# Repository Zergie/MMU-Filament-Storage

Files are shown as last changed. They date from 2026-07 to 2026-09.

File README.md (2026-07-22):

<p align="center">
  YAMMU: eight filament paths in twin drawers inside one heated enclosure
</p>

<p align="center">
  <a href="https://discord.gg/QSjW5CMHZC">Join the YAMMU Discord</a>
  
  
</p>

YAMMU is an open, Voron-inspired multi-material unit for FFF printers. It combines eight filament paths, enclosed heated storage, BLDC-driven loading, filament sensing, custom electronics, and Klipper-based control in one machine.

> [!IMPORTANT]
> **YAMMU is a work in progress.** The current goal is reliable loading and unloading before or at the start of a print. Multi-color and multi-material printing are planned, but are not the present focus.

## See the machine

| Complete enclosure | Twin spool carrier | Heated chamber | Custom electronics bay |
| :---: | :---: | :---: | :---: |
| YAMMU enclosure with two filament drawers | Two YAMMU filament spools on the carrier and feeder assembly | YAMMU heater mounted inside the sealed filament chamber | YAMMU electronics bay inside the lower enclosure |

## One system, four jobs

- **Store** — eight spools live in two enclosed drawers built around 2020 extrusion.
- **Dry** — the sealed filament chamber is heated for dry storage while printing.
- **Move** — two BLDC-driven feeders load filament through short inlet paths and toward the extruder.
- **Verify** — switches at the splitter and toolhead let the control system confirm filament progress.

<p align="center">
  Conceptual YAMMU filament path from eight enclosed spools through twin feeders and sensors to the toolhead
</p>

## Built as open hardware

The repository contains the mechanical, electrical, firmware, and assembly material needed to follow the project—not just product renders.

| Area | What is included | Start here |
| --- | --- | --- |
| Mechanical | STEP assembly, printable STLs, and panel DXFs | [CAD](./CAD) · [STLs](./STLs) · [DXFs](./Drawings_DXFs) |
| Electronics | Main, connector, and sensor-board source and manufacturing files | [PCB files](./PCB) - new version soon! |
| Firmware | RP2040 build notes and YAMMU configuration for Klipper / Happy Hare | [Firmware guide](./Firmware/README.md) - new version soon! |
| Assembly | Illustrated assembly manual | [Open the PDF](./Manual/Assembly.pdf) |

## Start exploring

1. Inspect the [STEP assembly](./CAD/Assembly.step) or browse the ready-to-print [STLs](./STLs).
2. Read the [assembly manual](./Manual/Assembly.pdf) to understand the current mechanical build.
3. (unfinished) Review the [PCB feature set](./PCB/README.md) and manufacturing files.
4. (unfinished) Follow the [firmware guide](./Firmware/README.md) for the current RP2040, Klipper, and Happy Hare setup.

## Current roadmap

<p align="center">
  YAMMU roadmap listing all v1.0 working-MMU goals and v1.1 heated-chamber and environmental-monitoring goals
</p>

[View v1.0 progress](https://github.com/Zergie/YAMMU/issues?q=is%3Aissue%20milestone%3Av1.0)
[View v1.1 progress](https://github.com/Zergie/YAMMU/issues?q=is%3Aissue%20milestone%3Av1.1)

## Help build YAMMU

The project especially needs help with prototype testing, CAD, electronics, firmware, and documentation. If you can test the current iteration or improve one part of the system, open an issue or pull request—or join the [YAMMU Discord](https://discord.gg/QSjW5CMHZC).

## Credits and related projects

YAMMU builds on ideas and parts from the wider open-source 3D-printing community, including [Voron Trident](https://github.com/VoronDesign/Voron-Trident), [ERCF v2](https://github.com/Enraged-Rabbit-Community/ERCF_v2), and several community designs documented in the repository history. Review source licenses before redistributing derived parts.

<details>
<summary><strong>Third-party parts and original licenses</strong></summary>

- [Voron Trident](https://github.com/VoronDesign/Voron-Trident) parts — GNU GPL v3
- [ERCF v2](https://github.com/Enraged-Rabbit-Community/ERCF_v2) parts — GNU GPL v3
- [Stronger Compact Spool Auto-Rewinder](https://www.printables.com/model/784434-stronger-compact-spool-auto-rewinder) by rans_1668459 — GNU GPL v2
- [Voron 2.4 front panel handle, hinge, and magnet latch](https://www.printables.com/model/371692-voron-24-front-panel-handle-hinge-magnet-latch/files) by Jason_116929 — CC BY-SA
- [Removable panel/door kit for Voron V2/Trident](https://www.printables.com/model/702768-kit-for-removable-panelsdoors-for-voron-v2trident-/files) by Victor Mateus Oliveira — GNU GPL v3
- [WAGO 221-415 extrusion mount](https://www.printables.com/model/869020-wago-221-415-extrusion-mount-1by5-and-2by5) by Artxime — GNU GPL v3
- [LRS-200 DIN rail mount](https://www.printables.com/model/254538-lrs-200-din-rail-mount) by CrazyIvan359 — Creative Commons 4.0

</details>

Other MMU projects worth exploring include [ERCF v2](https://github.com/Enraged-Rabbit-Community/ERCF_v2), [8-Track](https://github.com/ArmoredTurtle/8-Track-Raven-Alpha), [Primitive Infinite Spool System](https://github.com/Esoterical/PrinterMods/tree/main/Primitive%20Infinite%20Spool%20System), [TradRack](https://github.com/Annex-Engineering/TradRack), and Prusa MMU3.

## License

Repository content is provided under the [GNU General Public License v3.0](./LICENSE). Third-party parts retain their original licenses.

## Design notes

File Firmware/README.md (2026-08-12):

# Build and Flash Firmware Image

1. Refer to [klipper's official installation](https://www.klipper3d.org/Installation.html)

2. `Building the micro-controller` with the configuration shown below.
  * [*] Enable extra low-level configuration options
  * Micro-controller Architecture = `Raspberry Pi RP2040/RP235x`
  * IF USE BOOTLOADER ([see klipper docs](https://www.klipper3d.org/Bootloaders.html#stm32f103-micro-controllers-blue-pill-devices))
    * Bootloader offset = `offset of your bootloader`
  * ELSE
    * Bootloader offset = `No bootloader`
  * Communication interface = `USBSERIAL`
  * GPIO pins to set at micro-controller startup = `gpio4,gpio7`



3. Once the configuration is selected, press `q` to exit,  and "Yes" when  asked to save the configuration.
4. Run the command `make`
5. Flash the MCU
   * IF USE BOOTLOADER
     * Follow the instructions of your bootloader
   * ELSE IF USE NO BOOTLOADER
     * Unplug the Raspberry Pi
     * Hold `Boot` and plug in the Raspberry Pi
     * Run the command `make serialflash FLASH_DEVICE=/dev/serial/by-id/<YOUR USB ID>` for flashing via Serial or
     * OR Copy `~/klipper/out/klipper.uf2` via a windows pc

# Basic configuration
1. Run the `ls /dev/serial/by-id/*` command to get the correct ID number of the RP2040, and set the ID in `mmu.cfg`.
    ```
    [mcu]
    serial: /dev/serial/by-id/usb-1a86_USB_Serial-if00-port0
    restart_method: command
    ```
2. Refer to [klipper's official Config_Reference](https://www.klipper3d.org/Config_Reference.html) to configure the features you want.
3. Refer to [happy-hare's installation guide](https://github.com/moggieuk/Happy-Hare/wiki/Installation) to configure the basic printer settings.
4. In your `mmu/mmu_vars.cfg`, set the `mmu_gear_rotation_distances` variable to `1` for all gaters, as shown below:
    ```
    mmu_gear_rotation_distances: [1, 1, 1, 1, 1, 1, 1, 1]
    ```

# Calibration Steps

```mermaid
graph TD;
    Hardware_Working --> MMU_CALIBRATE_BLDC["MMU_CALIBRATE_BLDC<br/><span style='font-size:10px'>(to map pwm to rpm values))</span>"]
    MMU_CALIBRATE_BLDC --> MMU_CALIBRATE_GEAR["MMU_CALIBRATE_GEAR<br/><span style='font-size:10px'>(to accurately set rotation distance))</span>"]
    MMU_CALIBRATE_GEAR --> MMU_CALIBRATE_BOWDEN["MMU_CALIBRATE_ENCODER<br/><span style='font-size:10px'>(if MMU has an encoder)</span>"]
    MMU_CALIBRATE_BOWDEN --> MMU_CALIBRATE_GATES["MMU_CALIBRATE_GATES<br/><span style='font-size:10px'>(available if MMU has an encoder)</span>"]

    style Hardware_Working stroke-width:0px
```

## Calibate BLDC
Before calibrating the gear rotation distance, calibrate the BLDC motor. Select a gate belonging to the BLDC unit you want to calibrate and run:

`MMU_CALIBRATE_BLDC MOTOR=<0 or 1>`

The calibration automatically determines the minimum usable PWM and measures the motor RPM across the available PWM range. The resulting PWM-to-RPM map is saved to mmu_vars.cfg and is used by Happy Hare for accurate BLDC speed control. Repeat the calibration for both BLDC units.

## Calibrate rotation distance
see [Happy Hare wiki](https://github.com/moggieuk/Happy-Hare/wiki/MMU-Calibration-TypeB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)

## Calibrate bowden length
see [Happy Hare wiki](https://github.com/moggieuk/Happy-Hare/wiki/MMU-Calibration-TypeB#---step-3-calibrate-bowden-length)

## Calibrating gates
see [Happy Hare wiki](https://github.com/moggieuk/Happy-Hare/wiki/MMU-Calibration-TypeB#---step-4-calibrating-individual-gates)

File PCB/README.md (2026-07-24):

<p align="center">
  YAMMU Control Board v05 — KiCad source, fabrication outputs, SMT assembly data, and an interactive BOM
</p>

<p align="center">
  
  
  
</p>

This directory contains the editable KiCad design and manufacturing data for the **YAMMU Control Board v05**. The 100 × 60 mm board brings the RP2040 controller, motor and heater control, fan outputs, servos, end stops, analog sensors, I²C, and power regulation onto one board.

## Board preview

| Component side | Solder side |
| :---: | :---: |
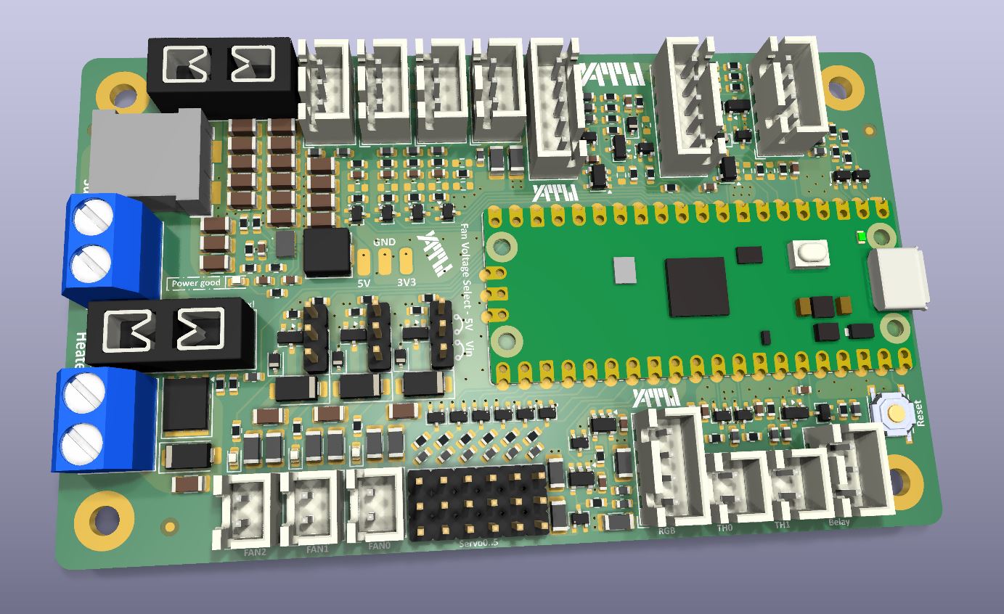
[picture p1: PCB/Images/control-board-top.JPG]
3D render of the populated YAMMU Control Board component side
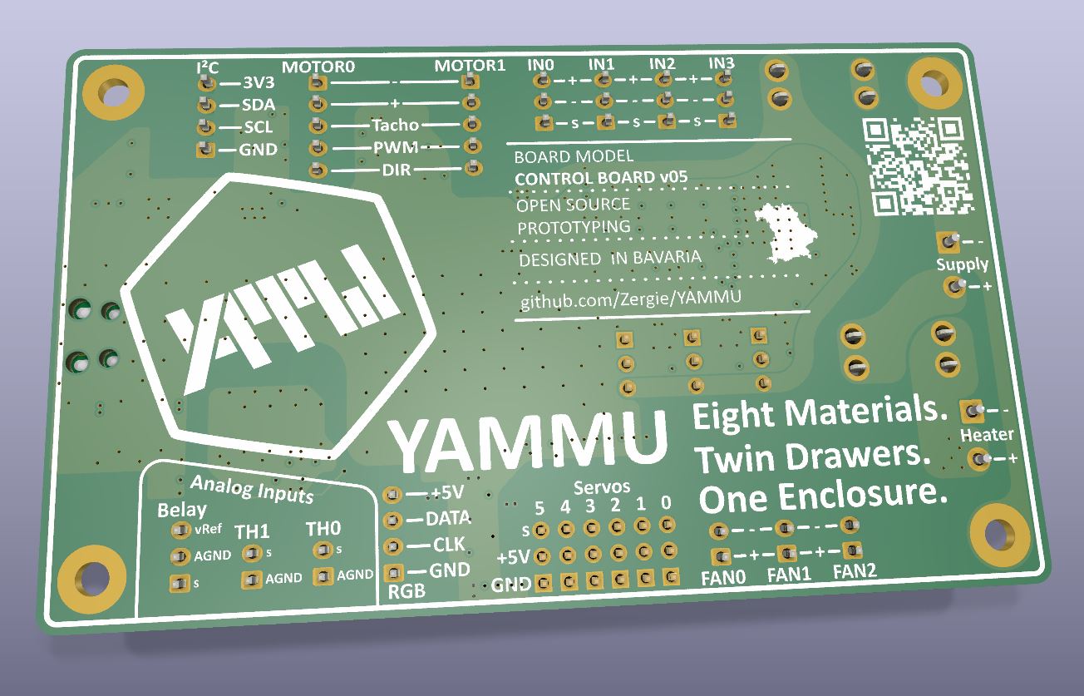
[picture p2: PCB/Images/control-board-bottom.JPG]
3D render of the YAMMU Control Board solder side and connector labels
|  |  |

| Design fact | Checked-in value |
| --- | --- |
| Board revision | `05` |
| KiCad format | KiCad `9.0` |
| Outline | approximately `100 × 60 mm` |
| Board thickness | `1.6 mm` |
| Copper stack | `4 layers` |
| Assembly side | Top-side placement data; the bottom placement file contains no components |
| Placement records | 220 top-side entries |
| DRC snapshot | [0 violations, 0 unconnected pads](./ControlBoard/DRC.rpt) on 2026-07-11 |

## Find the right file

| Use | File |
| --- | --- |
| Open the complete design | [`YAMMU_ControlBoard_v05.kicad_pro`](./ControlBoard/YAMMU_ControlBoard_v05.kicad_pro) |
| Edit the PCB | [`YAMMU_ControlBoard_v05.kicad_pcb`](./ControlBoard/YAMMU_ControlBoard_v05.kicad_pcb) |
| Read the schematic | [Schematic PDF](./ControlBoard/OutputJob/Schematics/YAMMU_ControlBoard_v05.pdf) |
| Manufacture bare boards | [Gerber + drill ZIP](./ControlBoard/OutputJob/YAMMU_ControlBoard_v05_Gerber.zip) |
| Order SMT assembly | [BOM](./ControlBoard/OutputJob/BOM/YAMMU_ControlBoard_v05_BOM.xlsx) + [top-side CPL](./ControlBoard/OutputJob/Centroid/TopCentroid.xlsx) |
| Hand-assemble or inspect | [Interactive BOM](./ControlBoard/Interactive%20Bom/ibom.html) |
| Check component outlines | [Front fabrication drawing](./ControlBoard/OutputJob/BestPlan/YAMMU_ControlBoard_v05-F_Fab.pdf) · [Back fabrication drawing](./ControlBoard/OutputJob/BestPlan/YAMMU_ControlBoard_v05-B_Fab.pdf) |

<p align="center">
  YAMMU PCB manufacturing flow from KiCad source to Gerbers, bare PCB fabrication, and optional SMT assembly using BOM and CPL files
</p>

## Order a bare PCB

[JLCPCB](https://jlcpcb.com/) is one example board house; the same release files can be used with another manufacturer. Prices, capabilities, and form labels change, so treat the provider's current documentation as authoritative.

1. Open the board house's PCB quote page and upload the **ZIP itself**. For JLCPCB, use the [Gerber + drill ZIP](./ControlBoard/OutputJob/YAMMU_ControlBoard_v05_Gerber.zip).
2. Compare the detected result with the design: approximately **100 × 60 mm**, **4 copper layers**, and **1.6 mm** finished thickness. Select the required material, copper weight, solder-mask color, surface finish, quantity, and any other fabrication options; do not rely on automatic detection for choices that are not encoded in the Gerbers.
3. Open the provider's Gerber viewer. Inspect all four copper layers, the continuous board outline, all drills and slots, both masks, and both silkscreens.
4. Save the item to the cart, review manufacturing warnings, shipping, tax, and lead time, then submit the order.

JLCPCB's current walkthrough is available in its [official PCB ordering guide](https://jlcpcb.com/help/article/how-do-i-place-an-order). The online preview is a useful final check, but it does not replace reviewing the KiCad design and release contents.

## Order SMT assembly

An assembly order needs three data sets:

| Upload | What it tells the assembler | This repository |
| --- | --- | --- |
| **Gerbers + drills** | How to fabricate the bare board | [`YAMMU_ControlBoard_v05_Gerber.zip`](./ControlBoard/OutputJob/YAMMU_ControlBoard_v05_Gerber.zip) |
| **BOM** | Which part belongs at each reference designator | [`YAMMU_ControlBoard_v05_BOM.xlsx`](./ControlBoard/OutputJob/BOM/YAMMU_ControlBoard_v05_BOM.xlsx) |
| **CPL / centroid / pick-and-place** | Each component's X/Y position, rotation, and board side | [`TopCentroid.xlsx`](./ControlBoard/OutputJob/Centroid/TopCentroid.xlsx) |

The BOM contains `Designator`, `Comment`, `Footprint`, `Amount`, and `JLCPCB Part #` columns. The CPL contains `Designator`, `Mid X`, `Mid Y`, `Rotation`, and `Layer`. The reference designators must match between the two files.

For a JLCPCB PCBA order:

1. Start a PCB order, upload the corrected Gerber ZIP, and enable **PCB Assembly** before checkout.
2. Select top-side assembly. The current top CPL has 220 placement records. The bottom CPL has no components and is not used for assembly.
3. Upload the BOM and top-side CPL, then let the service process and match them.
4. Review every unmatched or substituted component. Confirm value, package, manufacturer part number or JLCPCB/LCSC part number, stock, and quantity. “No part selected” means that item will not be fitted.
5. Inspect the placement preview at high zoom. Check connector orientation, polarized capacitors and diodes, IC pin 1, rotations, and the board origin. Do not approve the job solely because the files were accepted.
6. Confirm which through-hole, module, connector, or otherwise unsupported parts must be installed by hand after delivery.

JLCPCB documents the current flow in its [official PCBA ordering guide](https://jlcpcb.com/help/article/how-do-i-place-a-pcba-order). Its [BOM/CPL preparation guidance](https://jlcpcb.com/help/article/advice-for-bom-and-cpl-files-preparation) explains reference matching, supported headers, coordinates, and common upload problems.

> [!IMPORTANT]
> Component availability and assembly capabilities are live manufacturing constraints, not properties of this repository. Always re-check part matches and the placement preview for the specific order.

## Use the Interactive BOM

[`Interactive Bom/ibom.html`](./ControlBoard/Interactive%20Bom/ibom.html) is a self-contained browser view generated from the PCB. Download or clone the repository and open the file locally—no KiCad installation or web server is required.

Use it to:

- click a BOM row and highlight the matching footprints on the board;
- pan, zoom, and switch between board sides;
- search by reference, value, or footprint;
- group identical parts and inspect their board locations;
- tick off parts while hand-placing or checking a finished assembly.

The Interactive BOM is an **assembly and inspection aid**. It is not the BOM spreadsheet, not pick-and-place data, and not a file to upload for SMT assembly. Use the `.xlsx` BOM and CPL listed above for the manufacturer.

## License

This PCB is part of the YAMMU open-hardware project. See the repository's [GNU GPL v3.0 license](../LICENSE).

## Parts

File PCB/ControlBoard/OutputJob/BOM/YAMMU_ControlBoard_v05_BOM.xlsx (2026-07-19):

Designator | Comment | Footprint | Amount | JLCPCB Part #
C1,C3 | 1nF | Capacitor_SMD:C_0603_1608Metric | 2 | C1588
C1.1,C1.2,C1.3,C1.4,C1.5,C1.6,C1.7 | 10µF 50V | Capacitor_SMD:C_1206_3216Metric | 7 | C13585
C2,C4,C5,C14 | 10nF | Capacitor_SMD:C_0603_1608Metric | 4 | C57112
C2.1,C2.2,C2.3,C2.4 | 100µF/6,3V | Capacitor_SMD:C_1206_3216Metric | 4 | C15008
C3.1 | 100nF | Capacitor_SMD:C_0603_1608Metric | 1 | C14663
C4.1 | 47pF | Capacitor_SMD:C_0603_1608Metric | 1 | C1671
C5.1 | 3,3nF | Capacitor_SMD:C_0603_1608Metric | 1 | C1613
C6,C15,C18,C19 | 2,2µF | Capacitor_SMD:C_1206_3216Metric | 4 | C50254
C7,C8,C9,C10,C11,C12,C13 | 10µF 50V | Capacitor_SMD:C_1206_3216Metric | 7 | C13585
C16,C17,C20,C21,C22,C23,C24 | 100nF | Capacitor_SMD:C_0603_1608Metric | 7 | C14663
D1,D2,D3,D4,D6,D7,D8,D9,D11,D15,D17,D21,D22,D23,D24,D25,D31,D32,D33,D34,D35 | BAT54SW | Package_TO_SOT_SMD:SOT-323_SC-70 | 21 | C78606
D5,D10 | BZT52C4V7S | Diode_SMD:D_SOD-323 | 2 | C19077439
D12,D16,D18,D27,D28 | RED | LED_SMD:LED_0603_1608Metric | 5 | C2286
D13,D19,D29 | 1N4148 | Diode_SMD:D_SOD-323 | 3 | C2128
D14,D20,D26,D30 | SS34 | Diode_SMD:D_SMA | 4 | C8678
F1,F2 | 10A,3A | Fuse:Fuseholder_Blade_Mini_Keystone_3568 | 2 | C19727305
FB1,FB2,FB3,FB4,FB5,FB6,FB7,FB8,FB9,FB10,FB11,FB13,FB15,FB16,FB18,FB20,FB21,FB22,FB23,FB24,FB25,FB26,FB34,FB36,FB38,FB39,FB40,FB41,FB42,FB43 | 600Ohm 200mA | Inductor_SMD:L_0603_1608Metric | 30 | C1002
FB12,FB14,FB17,FB19,FB28,FB29,FB30,FB31,FB32,FB33,FB35,FB37 | 600Ohm 3A | Inductor_SMD:L_1206_3216Metric | 12 | C357023
IC1 | AP63356DV-7 | LocalParts:AP63356DV7 | 1 | C2157973
IC2 | RaspberryPi_Pico | Module:RaspberryPi_Pico_SMD_HandSolder | 1 | C7203002
J1,J4,J7,J11,J23 | Conn_01x03 | Connector_JST:JST_XH_B3B-XH-A_1x03_P2.50mm_Vertical | 5 | C7429633
J2,J5 | Conn_01x05 | Connector_JST:JST_XH_B5B-XH-A_1x05_P2.50mm_Vertical | 2 | C7429635
J3,J6,J10,J13,J15,J17 | Conn_01x03_Pin | LocalParts:PinHeader_1x03_P2.54mm_Vertical_HighDensity | 6 | C49257
J8,J12,J14,J16,J20 | Conn_01x02 | Connector_JST:JST_XH_B2B-XH-A_1x02_P2.50mm_Vertical | 5 | C18077833
J9,J19 | Screw_Terminal_01x02 | LocalParts:JL301-50002U02 | 2 | C395214
J21,J22 | Conn_01x04 | Connector_JST:JST_XH_B4B-XH-A_1x04_P2.50mm_Vertical | 2 | C7429634
JP2,JP3,JP4 | Jumper_3_Open | LocalParts:PinHeader_1x03_P2.54mm_Vertical_HighDensity | 3 | C49257
L1 | 6,8µH | Inductor_SMD:L_APV_APH0530 | 1 | C325965
L2 | 1kΩ@100MHz 2 6A 80V | LocalParts:ACM1211 | 1 | C41556
Q1,Q2 | 2N7002 | Package_TO_SOT_SMD:SOT-23 | 2 | C8545
Q3,Q4,Q6 | AO3400A | Package_TO_SOT_SMD:SOT-23-3 | 3 | C20917
Q5 | HY1904C2 | Package_DFN_QFN:PQFN-8-EP_6x5mm_P1.27mm_Generic | 1 | C358116
R1.1 | 105K | Resistor_SMD:R_0603_1608Metric | 1 | C16840
R2.1 | 20K | Resistor_SMD:R_0603_1608Metric | 1 | C4184
R3,R6,R10,R16,R19,R23,R28,R39 | 150K | Resistor_SMD:R_0603_1608Metric | 8 | C22807
R3.1 | 47K | Resistor_SMD:R_0603_1608Metric | 1 | C25819
R4,R5,R17,R18,R29,R40 | 10K | Resistor_SMD:R_0603_1608Metric | 6 | C25804
R4.1 | 10K | Resistor_SMD:R_0603_1608Metric | 1 | C25804
R5.1 | 38K3 | Resistor_SMD:R_0603_1608Metric | 1 | C23034
R8,R9,R11,R21,R22,R24,R32,R42,R47,R50,R57,R58 | 220R | Resistor_SMD:R_0603_1608Metric | 12 | C22962
R12,R25,R33,R43,R52,R55,R60,R62 | 100R | Resistor_SMD:R_0603_1608Metric | 8 | C22775
R13,R26,R34,R44,R45,R48,R53,R56 | 47K | Resistor_SMD:R_0603_1608Metric | 8 | C25819
R27,R31,R38,R54 | 1K | Resistor_SMD:R_0603_1608Metric | 4 | C21190
R36,R64 | 0R | Resistor_SMD:R_0603_1608Metric | 2 | C21189
R46,R49,R59,R61,R63 | 4K7 | Resistor_SMD:R_0603_1608Metric | 5 | C23162
R51 | 20K | Resistor_SMD:R_0603_1608Metric | 1 | C4184
SW1 | SW_MEC_5E | LocalParts:SW_TS-1187A-B-A-B | 1 | C318884
U1,U2 | SN74AHCT1G86DBVR | Package_TO_SOT_SMD:SOT-23-5 | 2 | C43417
U3 | LM4040A30IDBZR | Package_TO_SOT_SMD:SOT-23 | 1 | C9409
U4,U5 | SN74AHCT1G125DBVR | Package_TO_SOT_SMD:SOT-23-5 | 2 | C20617903

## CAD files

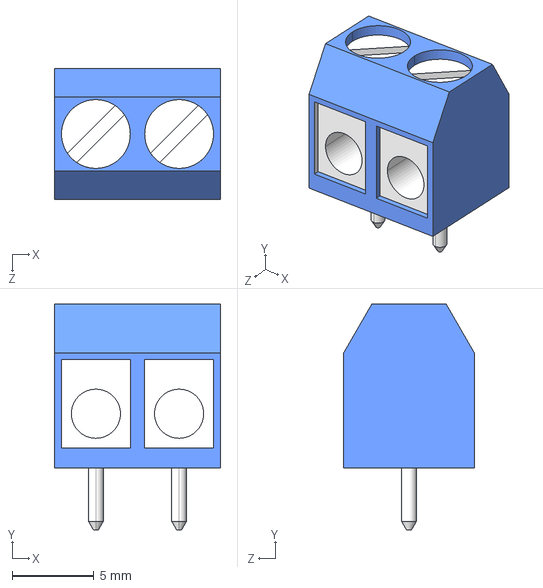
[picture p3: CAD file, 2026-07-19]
PCB/ControlBoard/LocalParts/3D/JL301-50002U02.stp
10.2 x 13.8 x 8.00 mm

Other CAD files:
STLs/BackGrill/back_grill_mount.stl
STLs/ElectronicsBay/DIN_center_support_x3.stl
STLs/ElectronicsBay/Nut5/cable_frame_anchor_x4.stl
STLs/ElectronicsBay/Nut6/DIN_corner_frame_mount_x4.stl
STLs/Feeder/motor_housing_c_x2.stl
STLs/Frame/Nut5/blind_joint_plug_I_x20.stl
STLs/Frame/Nut6/blind_joint_plug_x22.stl
STLs/Heater_200/heater_case_lower.stl
STLs/Panels/bottom_panel_hinge_x2.stl
STLs/Panels/Double_Pane/midspan_clip_10mm_x15.stl
STLs/Panels/Front_Doors/door_hinge_a_x2.stl
STLs/Panels/Single_Pane/corner_clip_6mm_x16.stl
STLs/Skirt/[a]_corner_baseplate_a_x2.stl
STLs/Skirt/Nut5/PSU.stl
STLs/Skirt/Nut6/side_a_x2.stl
STLs/SpoolCarrier/Ptfe_Splitter/ptfe_sleeve_x8.stl
STLs/SpoolCarrier/Rewinder/clutch_x8.stl
PCB/ControlBoard/LocalParts/3D/AP63356DV-7.stp
PCB/ControlBoard/LocalParts/3D/TS-1187A-B-A-B.step
PCB/ControlBoard/LocalParts/3D/acm1211.step
STLs/BackGrill/back_grill.stl
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

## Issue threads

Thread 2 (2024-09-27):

Finish Integrated Spool Rewinder

Zergie, 2024-09-27:
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

Need to verify the Integrated Spool Rewinder works as intended. It should be able to roll up the filament when the unload or eject command is triggered. The usable length of the filament tube should be between 1 and 1.5 meters.

If not able:
- may increase spring thickness
- may switch to spring steel springs ?

Zergie, 2024-11-20:
#Todo
## Fix Clearance
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

Closed 2024-11-22.

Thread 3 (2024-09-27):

Support Extruder while Printing

Zergie, 2024-09-27:
The MMU does put additional strain on the extruder. It should be possible to support the extruder with the BLDC-Motor.

To control the motor speed, it should be possible to use a modified "Belay Sensor" with a linear potentiometer instead of switches.
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

As how to implement that in klipper is open.

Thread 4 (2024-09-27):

Add Dummy Belay Sensor

Zergie, 2024-09-27:
To allow #3 we have an opening for a Belay style sensor on the back. But for v1.0 we need a dummy plate that only guides the filament outside without further functionality.

Zergie, 2025-04-14:
It seams the belay sensor is somewhat essential for Operation. Because of resistance in the filament path.

Closed 2025-04-14.

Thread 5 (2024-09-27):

Add desiccant container

Zergie, 2024-09-27:
For drying filament, we need an easy to user desiccant container.

# Option One
Modified (or even unmodified?) Nevermore V6.

# Option Two
A model designed to be easily mounted on a extrusion.

# Mounting position
Bottom back extrusion, blowing upward.

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

Zergie, 2025-04-14:
We will be using a Nevermore V6 .

Closed 2025-04-14.

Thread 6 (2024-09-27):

Add Heat Protection to Upper Back Filament Spools

Zergie, 2024-09-27:
It would be beneficial to have a heater fan shroud or a blade that redirects hot air to prevent the upper back filament spools from overheating.

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

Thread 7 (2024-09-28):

Remove JST Connector from all models

Zergie, 2024-09-28:
The JST Connector is hard to assemble. Most parts are pretty thigh, so mistakes result in disassembly of the hole Part.

Closed 2024-09-30.

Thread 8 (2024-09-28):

Fixup PTFE Splitter

Zergie, 2024-09-28:
- Orientate STL for printing
- Remove JST Connector and adds slot for cable ties

Zergie, 2024-09-29:
- ~Orientate STL for printing~
- ~Remove JST Connector and~ adds slot for cable ties
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

Closed 2024-10-16.

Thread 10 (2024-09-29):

PTFE Tube detaches

Zergie, 2024-09-29:
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
 The PTFE Tube keeps detaching when loading the filament quickly (MMU_LOAD).

Zergie, 2024-09-30:
Added ribs to grab the filament
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

Zergie, 2024-09-30:
Enhanced the grip on the filament by adding deeper grooves. But still needs testing.
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

Closed 2024-10-01.

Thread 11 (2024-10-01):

Finalize Firmware

Zergie, 2024-10-01:
Gcode macros
- Add endstop checks in _MMU
- skip loading when TOOL is already loaded in MMU_LOAD
- split into `mmu.cfg`, remove printer basics and module imports
- Add tools 3-7

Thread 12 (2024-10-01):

Add basic schematics for electronics

Zergie, 2024-10-01:
We need schematics for:
- endstops
- thermisters
- belay potentiometer
- Basic Wiring for the STM32

Additionally, we need a brief guide on how to configure and build Klipper for the STM32F103C8T6 or an equivalent model.

Closed 2024-11-22.

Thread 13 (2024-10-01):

Publish First Stage Filament Loader

Zergie, 2024-10-01:
Publish First Stage Filament Loader.

Work thats needs to be done:
- Remove thin bridge
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
- Test second side (Tool 2 & 3)
- The FSFL, as a standalone unit, is cumbersome. Therefore, the README should at least present the bigger picture, including some renderings.
- Update the BOM with the utilized:
    -  BLDC motors
    -  servos
    - Threaded M5 Rods
    - 5mm Shaft
    - Magnets

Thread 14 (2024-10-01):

Test the entire mechanical assembly.

Zergie, 2024-10-01:
Everything mechanical must be printed, assembled and tested. Emerging problems need to be solved.

Closed 2025-04-14.

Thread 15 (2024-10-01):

Rework README

Zergie, 2024-10-01:
- [x] outline current development status
- [x] ask for help
- [x] add renders of the project
- [x] section README
    - [x] Section Example Usage
        - [x] Manual Loading / Loading before printing (MMU_HOME / MMU_LOAD)
        - [x] Automatic Loading / Loading while printing ("Filament Start Gcode" in OrcaSlicer)
    - [x] Section Motivation
    - [x] Section "Keep Browsing"
        - [x] ERCF 1.1 / 2.0
        - [x] 8-Track https://github.com/ArmoredTurtle/8-Track-Raven-Alpha
        - [x] PISS
        - [x] TradRad
        - [x] Prusa MMU
- [x] add some nice badges => https://shields.io/
- [x] Expand wiki

Closed 2024-11-20.

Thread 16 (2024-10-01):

Gcode "T0" needs to pause the print

Zergie, 2024-10-01:
"T0" (and others) need to pause the printing process. Printing should resume once the filament has been correctly changed. If there is an error, the print should be aborted.

This must be done to manage your filament in applications such as Orca Slicer. When you select a filament there, 'Tx' commands are inserted into the .gcode file.

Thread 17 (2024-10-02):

Custom PCB for electronics

Zergie, 2024-10-02:
- [x] Design and Publish Schematics and EasyEDA link
- [x] Add DIN Rail Mount for the PCB
- [x] Add Gerber files
- [x] Add Files for PCB Assembly

Zergie, 2024-10-10:
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

Work in Progress ... waiting for pcb to arrive.

Know Bug, already :(
- no header for BLDC (2x PWM, 2x Tacho)

Zergie, 2024-10-11:
It seems I cannot get serial over USB working :( I tried three STM32F103C8T6 boards with the same result. All of them work when connected via CH340 serial breakout board using UART over USB. [This](https://www.aliexpress.com/item/1005006833541219.html?spm=a2g0o.order_list.order_list_main.10.3cdd1802y11ezP) [] is the  model (APM32F103CBT6 TYPE-C) I use.

Flashed the MSC bootloader with ST-Link:
https://www.klipper3d.org/Bootloaders.html#stm32f103stm32f072-with-msc-bootloader

Compiled klipper mcu with:
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

Copied that over to the STM32 via the provided usb flash drive.

When connected to the Raspberry Pi, it is recognized:
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

But when using this config:
printer.cfg
```
[include fluidd.cfg]
[include stm32.cfg]

[virtual_sdcard]
path: /home/user/printer_data/gcodes
on_error_gcode: CANCEL_PRINT

[respond]
default_type: echo

[printer]
kinematics: none
max_velocity: 100
max_accel: 100
```
stm32.cfg
```
[mcu]
serial: /dev/serial/by-id/usb-Klipper_stm32f103xe_B55B5A1A00000000260DF001-if00
#baud: 115200
restart_method: command

[temperature_sensor STM32F103]
sensor_type: temperature_mcu
sensor_mcu: mcu

[fan_generic MF1]
pin: mcu:PB3
```

I get this error:
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

klippy.log
```
Build file /home/user/klipper/klippy/../.config(3668): Fri Oct 11 12:07:14 2024
========= Last MCU build config =========
CONFIG_LOW_LEVEL_OPTIONS=y
# CONFIG_MACH_AVR is not set
# CONFIG_MACH_ATSAM is not set
# CONFIG_MACH_ATSAMD is not set
# CONFIG_MACH_LPC176X is not set
CONFIG_MACH_STM32=y
# CONFIG_MACH_HC32F460 is not set
# CONFIG_MACH_RP2040 is not set
# CONFIG_MACH_PRU is not set
# CONFIG_MACH_AR100 is not set
# CONFIG_MACH_LINUX is not set
# CONFIG_MACH_SIMU is not set
CONFIG_BOARD_DIRECTORY="stm32"
CONFIG_MCU="stm32f103xe"
CONFIG_CLOCK_FREQ=72000000
CONFIG_USBSERIAL=y
CONFIG_FLASH_SIZE=0x10000
CONFIG_FLASH_BOOT_ADDRESS=0x8000000
CONFIG_RAM_START=0x20000000
CONFIG_RAM_SIZE=0x5000
CONFIG_STACK_SIZE=512
CONFIG_FLASH_APPLICATION_ADDRESS=0x8002000
CONFIG_STM32_SELECT=y
CONFIG_MACH_STM32F103=y
# CONFIG_MACH_STM32F207 is not set
# CONFIG_MACH_STM32F401 is not set
# CONFIG_MACH_STM32F405 is not set
# CONFIG_MACH_STM32F407 is not set
# CONFIG_MACH_STM32F429 is not set
# CONFIG_MACH_STM32F446 is not set
# CONFIG_MACH_STM32F765 is not set
# CONFIG_MACH_STM32F031 is not set
# CONFIG_MACH_STM32F042 is not set
# CONFIG_MACH_STM32F070 is not set
# CONFIG_MACH_STM32F072 is not set
# CONFIG_MACH_STM32G070 is not set
# CONFIG_MACH_STM32G071 is not set
# CONFIG_MACH_STM32G0B0 is not set
# CONFIG_MACH_STM32G0B1 is not set
# CONFIG_MACH_STM32G431 is not set
# CONFIG_MACH_STM32G474 is not set
# CONFIG_MACH_STM32H723 is not set
# CONFIG_MACH_STM32H743 is not set
# CONFIG_MACH_STM32H750 is not set
# CONFIG_MACH_STM32L412 is not set
# CONFIG_MACH_N32G452 is not set
# CONFIG_MACH_N32G455 is not set
# CONFIG_MACH_STM32F103x6 is not set
CONFIG_MACH_STM32F1=y
CONFIG_HAVE_STM32_USBFS=y
CONFIG_HAVE_STM32_CANBUS=y
# CONFIG_STM32F103GD_DISABLE_SWD is not set
CONFIG_STM32_DFU_ROM_ADDRESS=0
CONFIG_STM32_FLASH_START_2000=y
# CONFIG_STM32_FLASH_START_5000 is not set
# CONFIG_STM32_FLASH_START_7000 is not set
# CONFIG_STM32_FLASH_START_8000 is not set
# CONFIG_STM32_FLASH_START_8800 is not set
# CONFIG_STM32_FLASH_START_9000 is not set
# CONFIG_STM32_FLASH_START_10000 is not set
# CONFIG_STM32_FLASH_START_800 is not set
# CONFIG_STM32_FLASH_START_1000 is not set
# CONFIG_STM32_FLASH_START_4000 is not set
# CONFIG_STM32_FLASH_START_0000 is not set
CONFIG_STM32_CLOCK_REF_8M=y
# CONFIG_STM32_CLOCK_REF_12M is not set
# CONFIG_STM32_CLOCK_REF_16M is not set
# CONFIG_STM32_CLOCK_REF_20M is not set
# CONFIG_STM32_CLOCK_REF_24M is not set
# CONFIG_STM32_CLOCK_REF_25M is not set
# CONFIG_STM32_CLOCK_REF_INTERNAL is not set
CONFIG_CLOCK_REF_FREQ=8000000
CONFIG_STM32F0_TRIM=16
CONFIG_STM32_USB_PA11_PA12=y
# CONFIG_STM32_SERIAL_USART1 is not set
# CONFIG_STM32_SERIAL_USART1_ALT_PB7_PB6 is not set
# CONFIG_STM32_SERIAL_USART2 is not set
# CONFIG_STM32_SERIAL_USART2_ALT_PD6_PD5 is not set
# CONFIG_STM32_SERIAL_USART3 is not set
# CONFIG_STM32_SERIAL_USART3_ALT_PD9_PD8 is not set
# CONFIG_STM32_CANBUS_PA11_PA12 is not set
# CONFIG_STM32_CANBUS_PA11_PB9 is not set
# CONFIG_STM32_MMENU_CANBUS_PB8_PB9 is not set
# CONFIG_STM32_MMENU_CANBUS_PD0_PD1 is not set
CONFIG_USB=y
CONFIG_USB_VENDOR_ID=0x1d50
CONFIG_USB_DEVICE_ID=0x614e
CONFIG_USB_SERIAL_NUMBER_CHIPID=y
CONFIG_USB_SERIAL_NUMBER="12345"

#
# USB ids
#
# end of USB ids

CONFIG_WANT_GPIO_BITBANGING=y
CONFIG_WANT_DISPLAYS=y
CONFIG_WANT_SENSORS=y
CONFIG_WANT_LIS2DW=y
CONFIG_WANT_LDC1612=y
CONFIG_WANT_HX71X=y
CONFIG_WANT_ADS1220=y
CONFIG_WANT_SOFTWARE_I2C=y
CONFIG_WANT_SOFTWARE_SPI=y
CONFIG_NEED_SENSOR_BULK=y
CONFIG_CANBUS_FREQUENCY=1000000
CONFIG_INITIAL_PINS=""
CONFIG_HAVE_GPIO=y
CONFIG_HAVE_GPIO_ADC=y
CONFIG_HAVE_GPIO_SPI=y
CONFIG_HAVE_GPIO_I2C=y
CONFIG_HAVE_GPIO_HARD_PWM=y
CONFIG_HAVE_STRICT_TIMING=y
CONFIG_HAVE_CHIPID=y
CONFIG_HAVE_STEPPER_BOTH_EDGE=y
CONFIG_HAVE_BOOTLOADER_REQUEST=y
CONFIG_INLINE_STEPPER_HACK=y
=======================
Build file /home/user/klipper/klippy/../out/klipper.dict(8089): Fri Oct 11 12:09:26 2024
Last MCU build version: v0.12.0-315-g8f361a15b
Last MCU build tools: gcc: (15:12.2.rel1-1) 12.2.1 20221205 binutils: (2.39-8+rpi1+18) 2.39
Last MCU build config: ADC_MAX=4095 BUS_PINS_i2c1=PB6,PB7 BUS_PINS_i2c1a=PB8,PB9 BUS_PINS_i2c2=PB10,PB11 BUS_PINS_spi1=PA6,PA7,PA5 BUS_PINS_spi1a=PB4,PB5,PB3 BUS_PINS_spi2=PB14,PB15,PB13 BUS_PINS_spi3=PB4,PB5,PB3 CLOCK_FREQ=72000000 MCU=stm32f103xe PWM_MAX=255 RESERVE_PINS_USB=PA11,PA12 STATS_SUMSQ_BASE=256 STEPPER_BOTH_EDGE=1
Build file /home/user/klipper/klippy/../out/klipper.elf(1033108): Fri Oct 11 12:10:33 2024
mcu 'mcu': Wait for identify_response
Traceback (most recent call last):
  File "/home/user/klipper/klippy/serialhdl.py", line 68, in _get_identify_data
    params = self.send_with_response(msg, 'identify_response')
             ^^^^^^^^^^^^^^^^^^^^^^^^^^^^^^^^^^^^^^^^^^^^^^^^^
  File "/home/user/klipper/klippy/serialhdl.py", line 262, in send_with_response
    return src.get_response([cmd], self.default_cmd_queue)
           ^^^^^^^^^^^^^^^^^^^^^^^^^^^^^^^^^^^^^^^^^^^^^^^
  File "/home/user/klipper/klippy/serialhdl.py", line 319, in get_response
    self.serial.raw_send_wait_ack(cmds[-1], minclock, reqclock,
  File "/home/user/klipper/klippy/serialhdl.py", line 254, in raw_send_wait_ack
    self._error("Serial connection closed")
  File "/home/user/klipper/klippy/serialhdl.py", line 61, in _error
    raise error(self.warn_prefix + (msg % params))
serialhdl.error: mcu 'mcu': Serial connection closed
```

Zergie, 2024-10-11:
Following [[Mcu: Serial connection closed](https://klipper.discourse.group/t/mcu-serial-connection-closed-timeout-on-connect-wait-for-identify-response/6645)](https://klipper.discourse.group/t/mcu-serial-connection-closed-timeout-on-connect-wait-for-identify-response/6645)

sudo dmesg -e
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

lsusb -tv
```
/:  Bus 01.Port 1: Dev 1, Class=root_hub, Driver=dwc_otg/1p, 480M
    ID 1d6b:0002 Linux Foundation 2.0 root hub
    |__ Port 1: Dev 2, If 0, Class=Hub, Driver=hub/5p, 480M
        ID 0bda:5411 Realtek Semiconductor Corp. RTS5411 Hub
        |__ Port 4: Dev 11, If 0, Class=Communications, Driver=cdc_acm, 12M
            ID 1d50:614e OpenMoko, Inc.
        |__ Port 4: Dev 11, If 1, Class=CDC Data, Driver=cdc_acm, 12M
            ID 1d50:614e OpenMoko, Inc.
```

Zergie, 2024-10-11:
Changing the baud rate as suggested [here](https://github.com/Klipper3d/klipper/issues/3047#issuecomment-656170448) does nothing.

Zergie, 2024-10-11:
I thought it is worth the shot: [reddit](https://www.reddit.com/r/klippers/comments/rmy182/comment/hppfmop/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)

But, when recompiled everything with:
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

I get:
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

So it seems "USB (on PA11/12)" should be right?

Zergie, 2024-10-11:
Flashing with 16KiB also results in:
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

Zergie, 2024-10-11:
Tested on second Raspberry Pi (BTT PI) => no serial connection :(

```
mcu 'stm32': Starting serial connect
mcu 'stm32': Timeout on connect
mcu 'stm32': Wait for identify_response
Traceback (most recent call last):
  File "/home/biqu/klipper/klippy/serialhdl.py", line 68, in _get_identify_data
    params = self.send_with_response(msg, 'identify_response')
  File "/home/biqu/klipper/klippy/serialhdl.py", line 262, in send_with_response
    return src.get_response([cmd], self.default_cmd_queue)
  File "/home/biqu/klipper/klippy/serialhdl.py", line 319, in get_response
    self.serial.raw_send_wait_ack(cmds[-1], minclock, reqclock,
  File "/home/biqu/klipper/klippy/serialhdl.py", line 254, in raw_send_wait_ack
    self._error("Serial connection closed")
  File "/home/biqu/klipper/klippy/serialhdl.py", line 61, in _error
    raise error(self.warn_prefix + (msg % params))
serialhdl.error: mcu 'stm32': Serial connection closed
```

Zergie, 2024-10-11:
Seems to be the [same](https://klipper.discourse.group/t/diy-stm32f103cbt6-apm32-klipper-can-not-connect/5083/4) problem, but no usable solution.

Also tried:
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

=> no success :(

Zergie, 2024-10-12:
Flashed without boot loader and SWD:
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

=> same result

Zergie, 2024-10-12:
Trying with katapult...

1. after flashing with ST-Link
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

2. make menuconfig
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

3.

Closed 2024-11-21.

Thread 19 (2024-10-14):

Add RPM Watchdog for BLDC motors

Zergie, 2024-10-14:
Add RPM monitoring of the BLDC motors, so in case of failure we can power down the hole printer.

Something like here: https://github.com/AndrewEllis93/Print-Tuning-Guide/blob/main/macros/fan_tach_monitor.cfg

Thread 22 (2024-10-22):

Improve Filament Path in the PTFE Splitter

Zergie, 2024-10-22:
A good way too reduce friction could be to have the PTFE tubes go all the way in to the crossing point, printing with nylon might also work since it has a low friction coefficient

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

We might want to think about including a PTFE tube cutting guide to get a really neat and tight splice of the tube sections.

Zergie, 2024-10-22:
- [ ] Open the cavity to ensure that filament dust can escape, preventing binding or blockages.
- [ ] Extend the tubes as far as possible.
- [ ] Consider making a jig to cut the PTFE tube so that all four sections align perfectly, ensuring there is no point along the run where the filament comes into contact with the plastic.

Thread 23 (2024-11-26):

Fix Electronics Issues

Zergie, 2024-11-26:
- [x] Restart via Klipper does not work (=> does work now, nothing has changed...)
- [x] RGB does not work (=> LED melted while soldering)
- [x] Test MF1
- [x] Test MF2
- [x] Test MF3
- [x] Test MF4
- [x] Test TH0
- [x] Test TH1
- [x] Test Belay
- [x] Test Motor1
- [x] Test Motor2
- [x] Test Endstops
- [x] Test I2c
- [x] Test Servos

Closed 2024-12-30.

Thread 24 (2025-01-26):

Fix PCB

Zergie, 2025-01-26:
# Replace 10nF with 10uF

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

Zergie, 2025-03-01:
Also: Make PCB Cheaper!!
- Rp2040 instead of stm32 (working usb)
- no 12V to 5V Voltage regulator
   - reduce leds to minimum (no onboard Neopixel anymore)

# Pins needed (26 GPIO max)
- 2 endstops ... use only one signal pin here?
- 2x 3 motor pins
- 4x servo
- 1 analog pin for belay
- 2 thermister
- 3 fan pins
- 1 heater pin
- 2 I2C
- 1 Neopixel header (powered by usb, no mosfet)
22

## Optional
- 2 servos (open/close inlet-/outlet-vent?)
- 1 Endstop (case open/closed)
- 2 Endstops (drawer fully back)
5

Closed 2025-04-12.

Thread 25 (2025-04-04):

Fix mechanical Issues

Zergie, 2025-04-04:
- [ ] PTFE Top Feeder Tube to tight
    - [x] CAD
    - [ ] Printed
- [ ] Disengaged Latches grind drive gear
    - [x] CAD
    - [ ] Printed

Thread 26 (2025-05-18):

Rp2040 Footprint is wrong

Zergie, 2025-05-18:
Needs holes

Closed 2025-06-01.

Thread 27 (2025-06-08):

Rethink Electronics

Zergie, 2025-06-08:
Let's rethink the electronics and filament path. The current configuration does not allow loading filament when the case is open and the drawer is extended. So in order to load filament, you need to:
- Open case
- Slide drawer out
- Insert spool
- Insert filament
- Slide drawer in
- Run filament loading macro

If for example the filament tip is not inserted deep enough, you need to slide the drawer out again. Also the power connections might not be as reliable as we want. So I would be better to eliminate these connectors so the servos and motors are always powered. Ideally this should also include the filament path.

Both would enable to slide the drawer out while printing and change or load a filament that is not printing at the moment. Also powering the motors should be more reliable.

Third, to simplify filament loading for the user, we could add a sensor before the bldc motor, that triggers the loading macro automatically.

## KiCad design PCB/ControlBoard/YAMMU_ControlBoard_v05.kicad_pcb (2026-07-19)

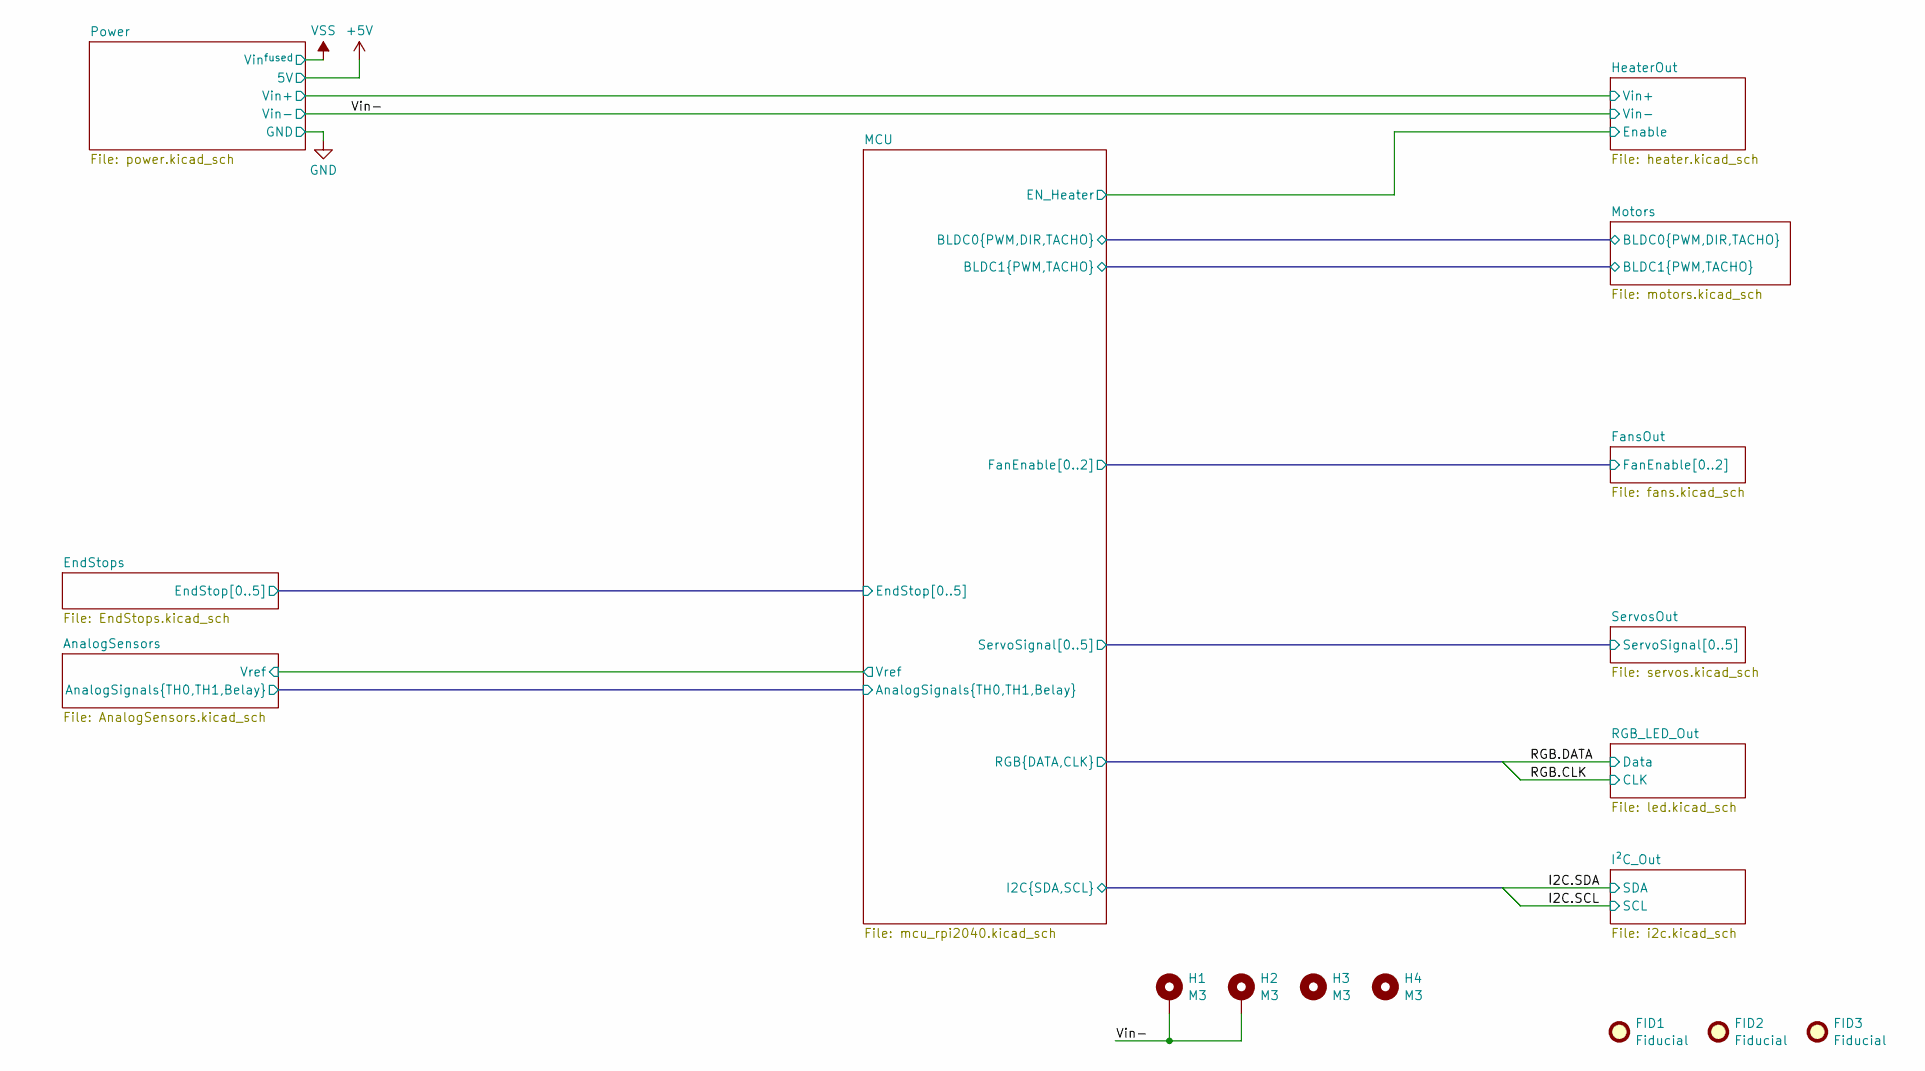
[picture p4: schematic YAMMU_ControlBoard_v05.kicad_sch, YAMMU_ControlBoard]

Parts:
FID1, FID2, FID3: Fiducial; Fiducial_1mm_Mask2mm
H1, H2, H3, H4: M3; MountingHole_3.2mm_M3_Pad

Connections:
/Vin-: H1.1, H2.1; also elsewhere on the board

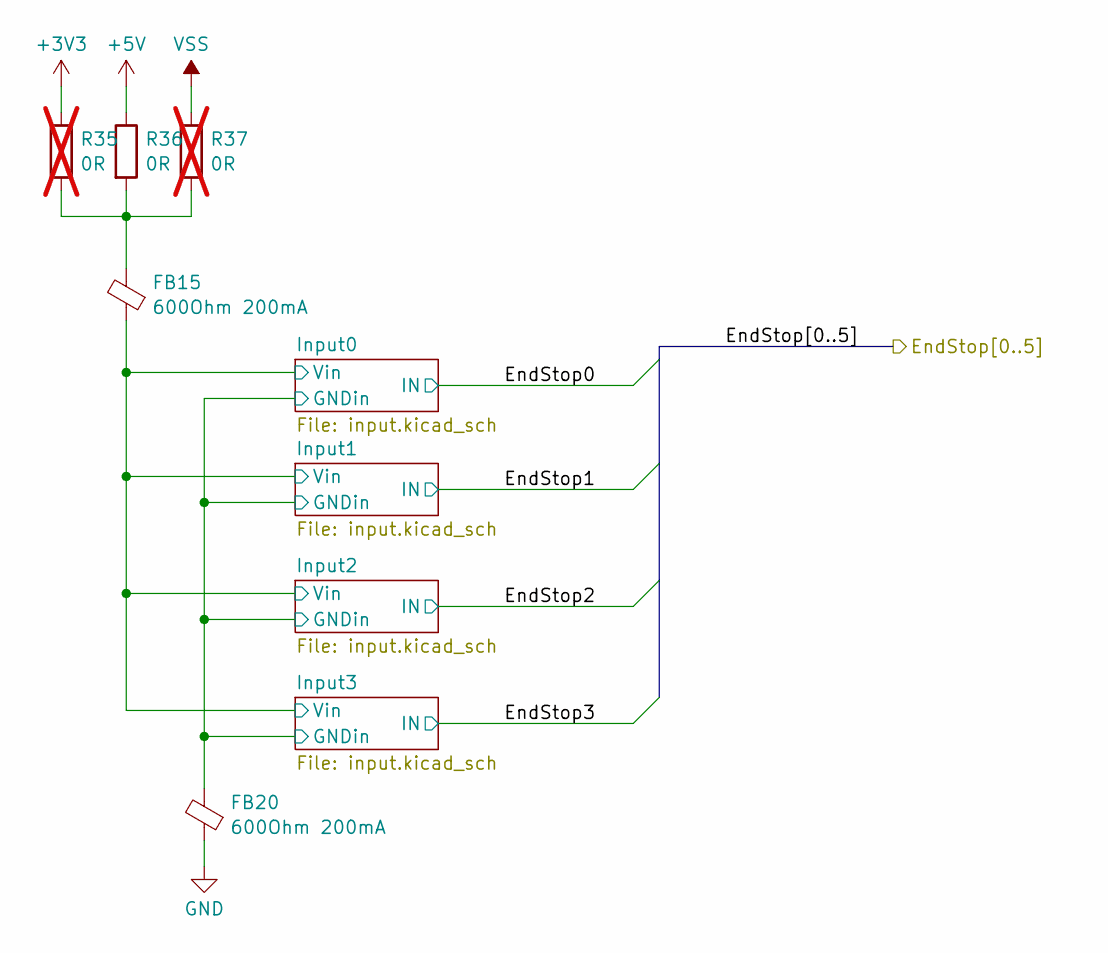
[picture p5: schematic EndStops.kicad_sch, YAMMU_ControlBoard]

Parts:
FB15, FB20: 600Ohm 200mA; L_0603_1608Metric; JLCPCB Part # C1002
R35, R37: 0R; R_0603_1608Metric; JLCPCB Part # C21189; not fitted
R36: 0R; R_0603_1608Metric; JLCPCB Part # C21189

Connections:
+3V3: R35.1; also elsewhere on the board
+5V: R36.1; also elsewhere on the board
/EndStops/Input0/GNDin: FB20.2; also elsewhere on the board
/EndStops/Input0/Vin: FB15.1; also elsewhere on the board
GND: FB20.1; also elsewhere on the board
unnamed: FB15.2, R35.2, R36.2, R37.2
VSS: R37.1; also elsewhere on the board

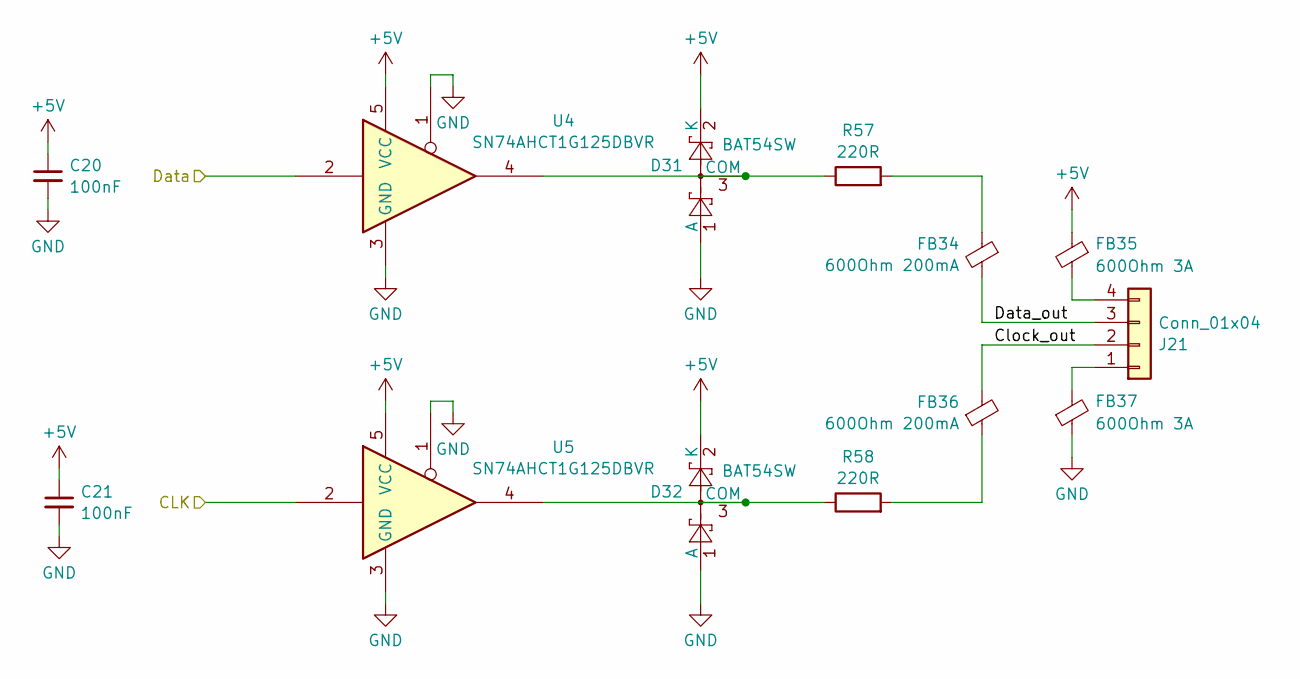
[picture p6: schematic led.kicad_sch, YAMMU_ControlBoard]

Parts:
C20, C21: 100nF; C_0603_1608Metric; JLCPCB Part # C14663
D31, D32: BAT54SW; SOT-323_SC-70; JLCPCB Part # C78606
FB34, FB36: 600Ohm 200mA; L_0603_1608Metric; JLCPCB Part # C1002
FB35, FB37: 600Ohm 3A; L_1206_3216Metric; JLCPCB Part # C357023
J21: Conn_01x04; JST_XH_B4B-XH-A_1x04_P2.50mm_Vertical; JLCPCB Part # C7429634
R57, R58: 220R; R_0603_1608Metric; JLCPCB Part # C22962
U4, U5: SN74AHCT1G125DBVR; SOT-23-5; JLCPCB Part # C20617903

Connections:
+5V: C20.1, C21.1, D31.2 (K), D32.2 (K), FB35.1, U4.5 (VCC), U5.5 (VCC); also elsewhere on the board
/MCU/RGB.CLK: U5.2; also elsewhere on the board
/MCU/RGB.DATA: U4.2; also elsewhere on the board
/RGB_LED_Out/Clock_out: FB36.2, J21.2
/RGB_LED_Out/Data_out: FB34.2, J21.3
GND: C20.2, C21.2, D31.1 (A), D32.1 (A), FB37.1, U4.1, U4.3 (GND), U5.1, U5.3 (GND); also elsewhere on the board
unnamed: D31.3 (COM), R57.1, U4.4
unnamed: D32.3 (COM), R58.1, U5.4
unnamed: FB34.1, R57.2
unnamed: FB36.1, R58.2
unnamed: FB37.2, J21.1
unnamed: FB35.2, J21.4

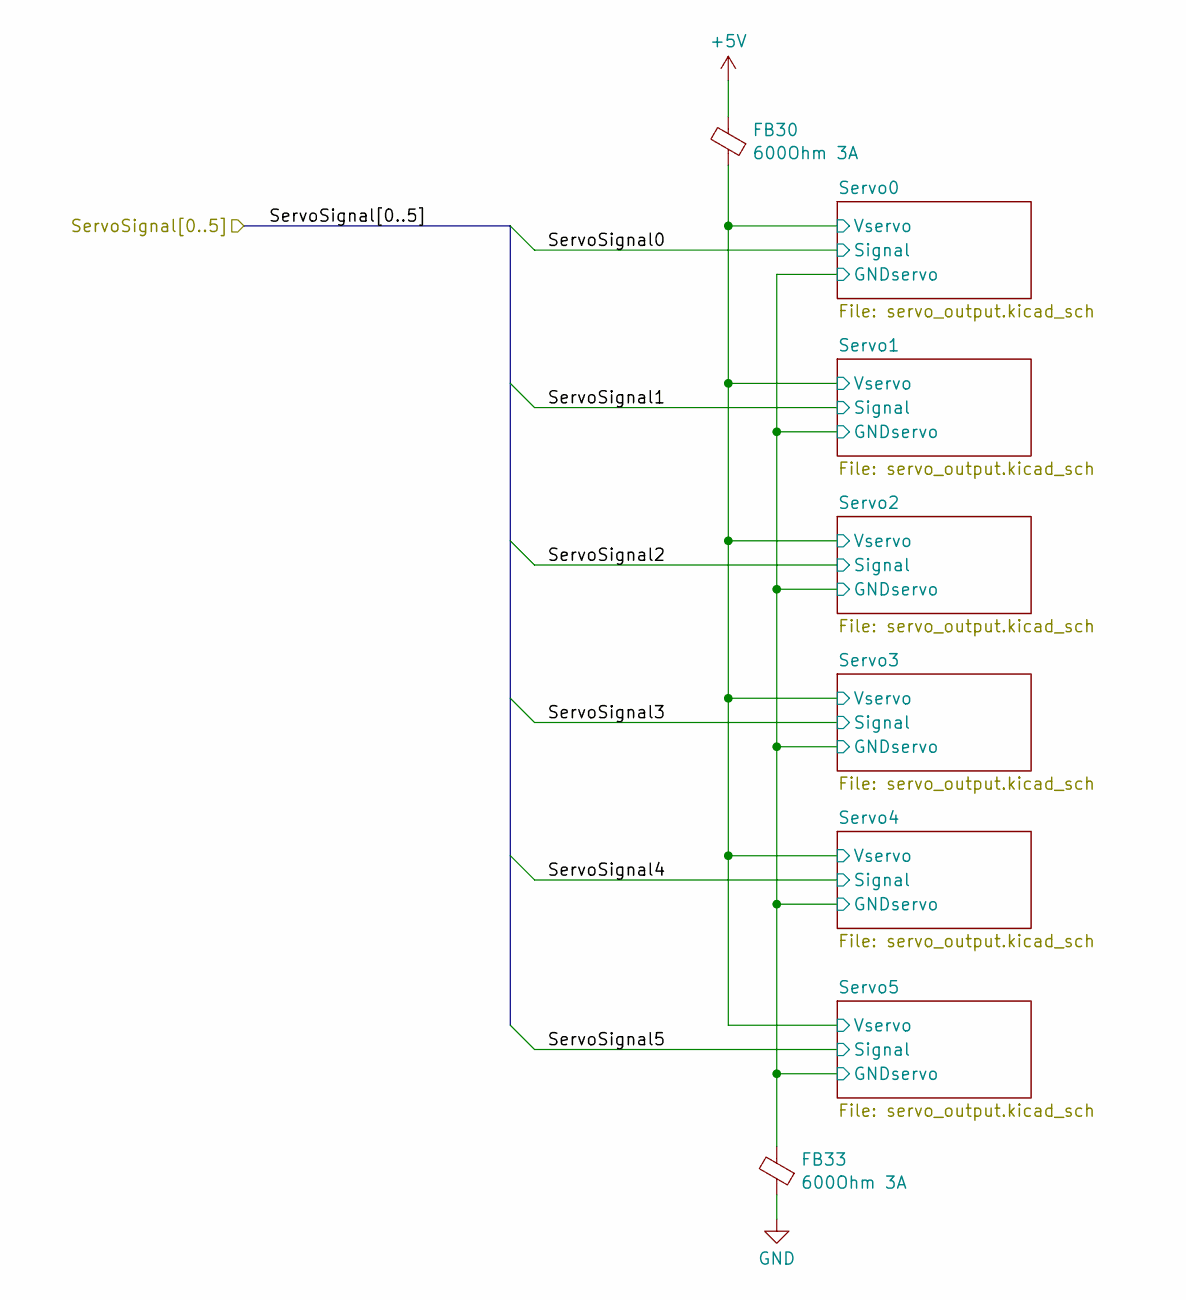
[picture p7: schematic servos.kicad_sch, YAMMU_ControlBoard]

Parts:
FB30, FB33: 600Ohm 3A; L_1206_3216Metric; JLCPCB Part # C357023

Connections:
+5V: FB30.2; also elsewhere on the board
/ServosOut/Servo0/GNDservo: FB33.2; also elsewhere on the board
/ServosOut/Servo0/Vservo: FB30.1; also elsewhere on the board
GND: FB33.1; also elsewhere on the board

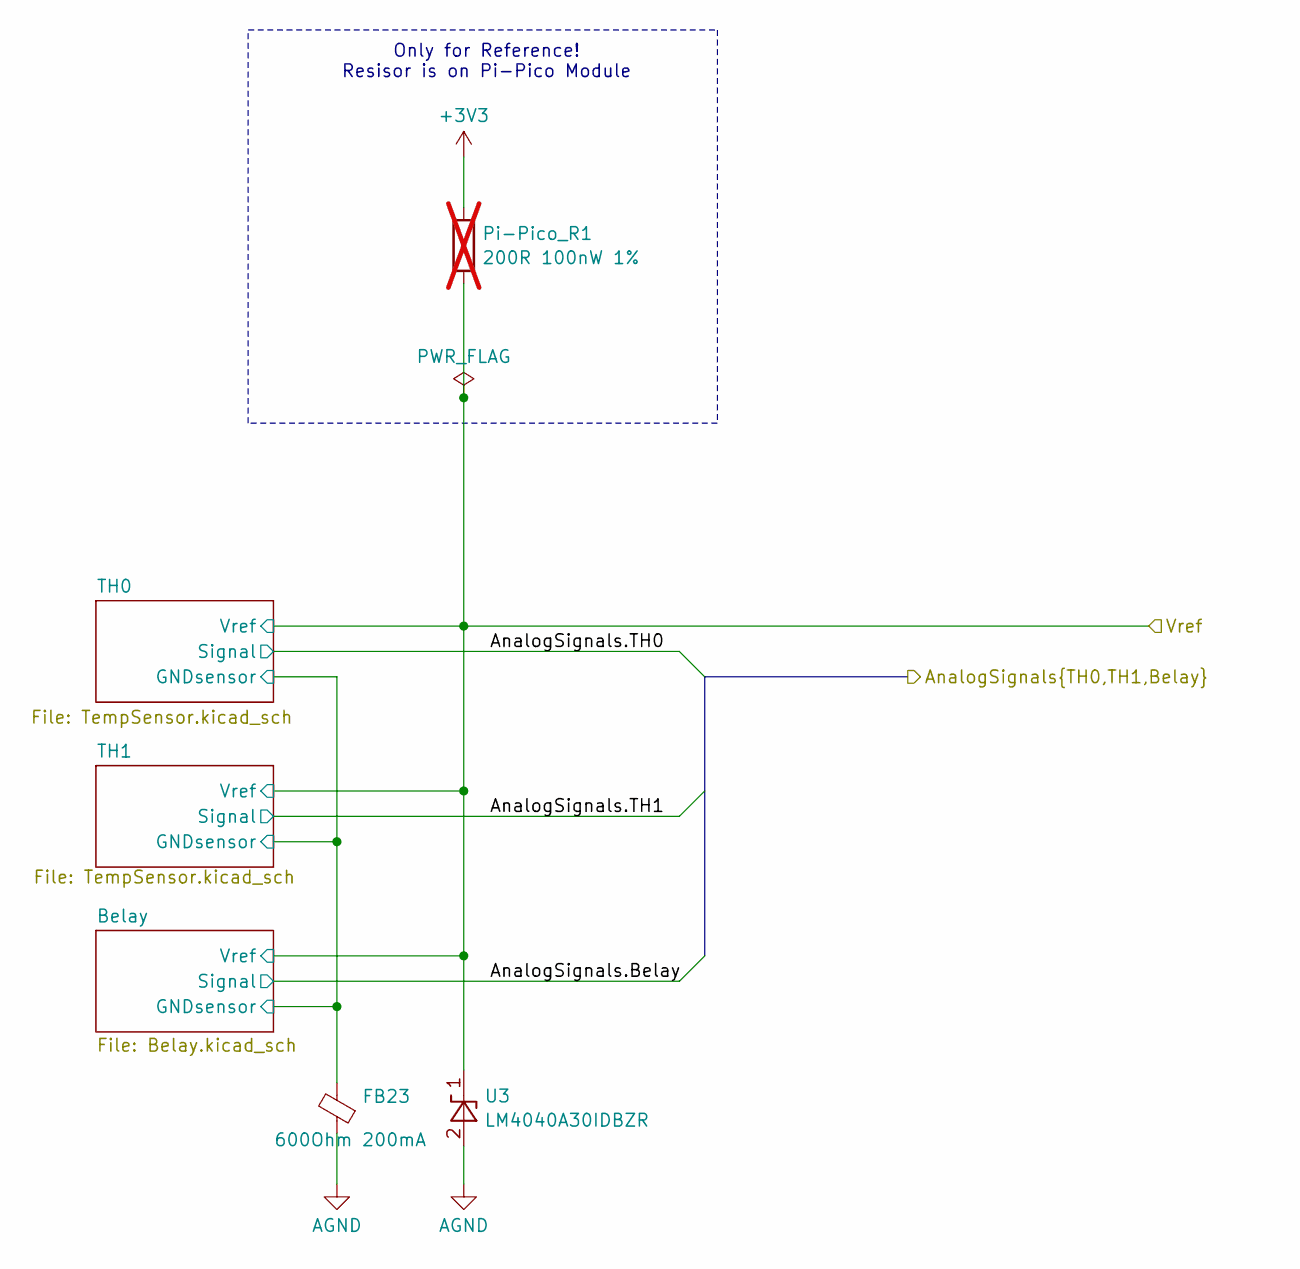
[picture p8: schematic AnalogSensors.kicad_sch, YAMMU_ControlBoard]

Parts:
FB23: 600Ohm 200mA; L_0603_1608Metric; JLCPCB Part # C1002
Pi-Pico_R1: 200R 100nW 1%; not fitted
U3: LM4040A30IDBZR; SOT-23; JLCPCB Part # C9409

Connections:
/AnalogSensors/Belay/GNDsensor: FB23.2; also elsewhere on the board
/AnalogSensors/Vref: Pi-Pico_R1.2, U3.1 (K); also elsewhere on the board
AGND: FB23.1, U3.2 (A); also elsewhere on the board

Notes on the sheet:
Only for Reference! Resisor is on Pi-Pico Module

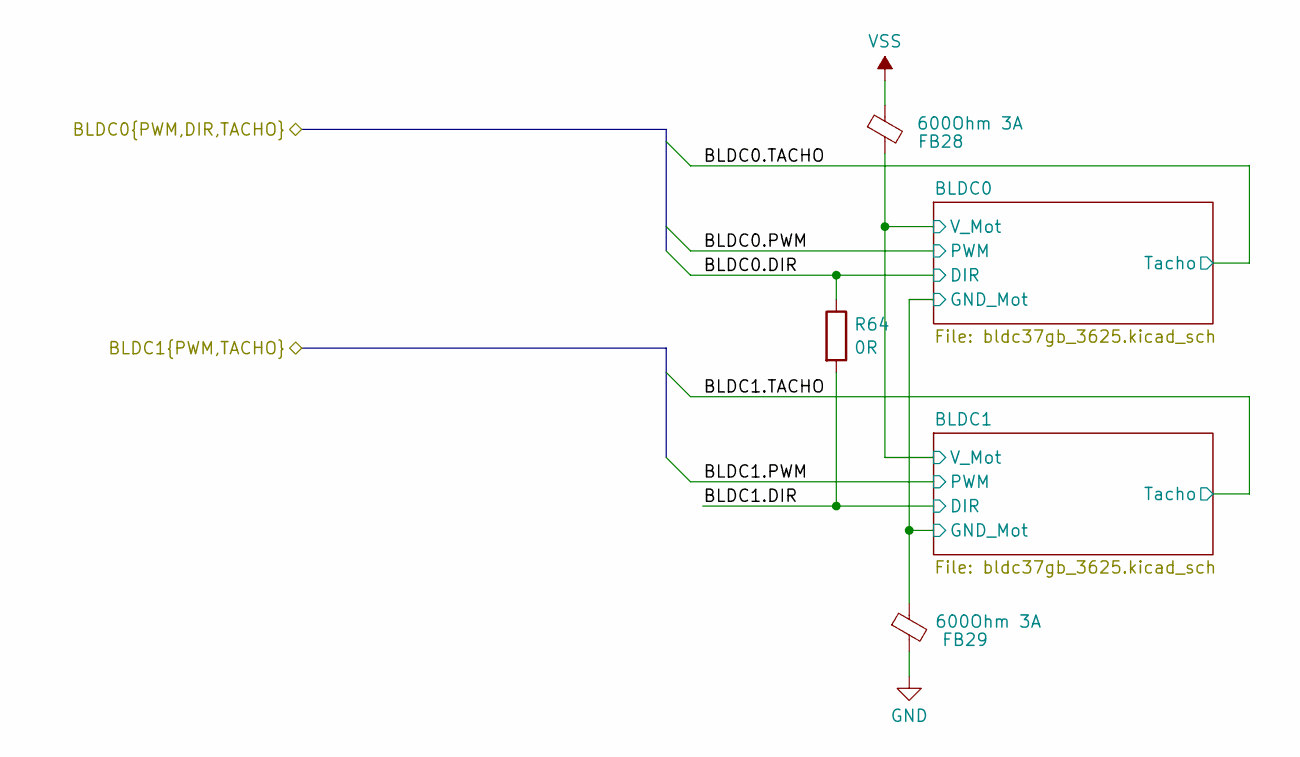
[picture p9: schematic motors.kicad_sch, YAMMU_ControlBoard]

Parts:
FB28, FB29: 600Ohm 3A; L_1206_3216Metric; JLCPCB Part # C357023
R64: 0R; R_0603_1608Metric; JLCPCB Part # C21189

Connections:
/MCU/BLDC0.DIR: R64.1; also elsewhere on the board
/Motors/BLDC0/GND_Mot: FB29.1; also elsewhere on the board
/Motors/BLDC0/V_Mot: FB28.2; also elsewhere on the board
/Motors/BLDC1.DIR: R64.2; also elsewhere on the board
GND: FB29.2; also elsewhere on the board
VSS: FB28.1; also elsewhere on the board

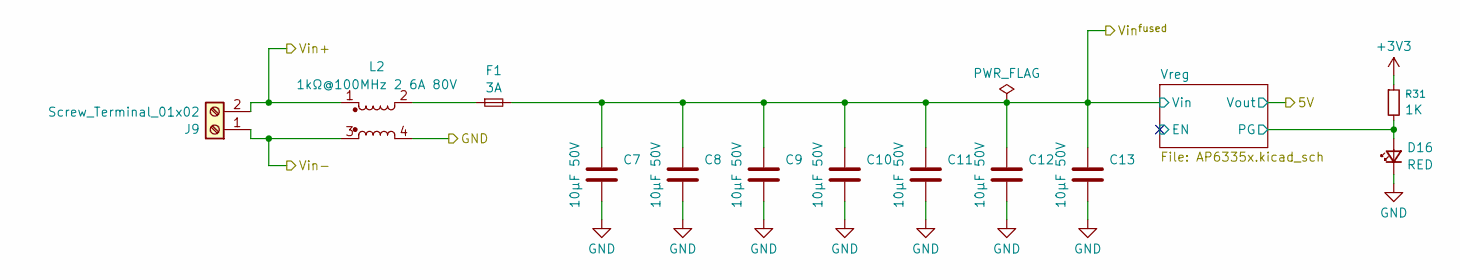
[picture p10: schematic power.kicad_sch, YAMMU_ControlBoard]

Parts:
C7, C8, C9, C10, C11, C12, C13: 10µF 50V; C_1206_3216Metric; JLCPCB Part # C13585
D16: RED; LED_0603_1608Metric; JLCPCB Part # C2286
F1: 3A; Fuseholder_Blade_Mini_Keystone_3568; JLCPCB Part # C19727305
J9: Screw_Terminal_01x02; JL301-50002U02; JLCPCB Part # C395214
L2: 1kΩ@100MHz 2 6A 80V; ACM1211; JLCPCB Part # C41556
R31: 1K; R_0603_1608Metric; JLCPCB Part # C21190

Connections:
+3V3: R31.1; also elsewhere on the board
/HeaterOut/Vin+: J9.2, L2.1; also elsewhere on the board
/Power/Vreg/PG: D16.2 (A), R31.2; also elsewhere on the board
/Vin-: J9.1, L2.3; also elsewhere on the board
GND: C7.2, C8.2, C9.2, C10.2, C11.2, C12.2, C13.2, D16.1 (K), L2.4; also elsewhere on the board
unnamed: F1.1, L2.2
VSS: C7.1, C8.1, C9.1, C10.1, C11.1, C12.1, C13.1, F1.2; also elsewhere on the board

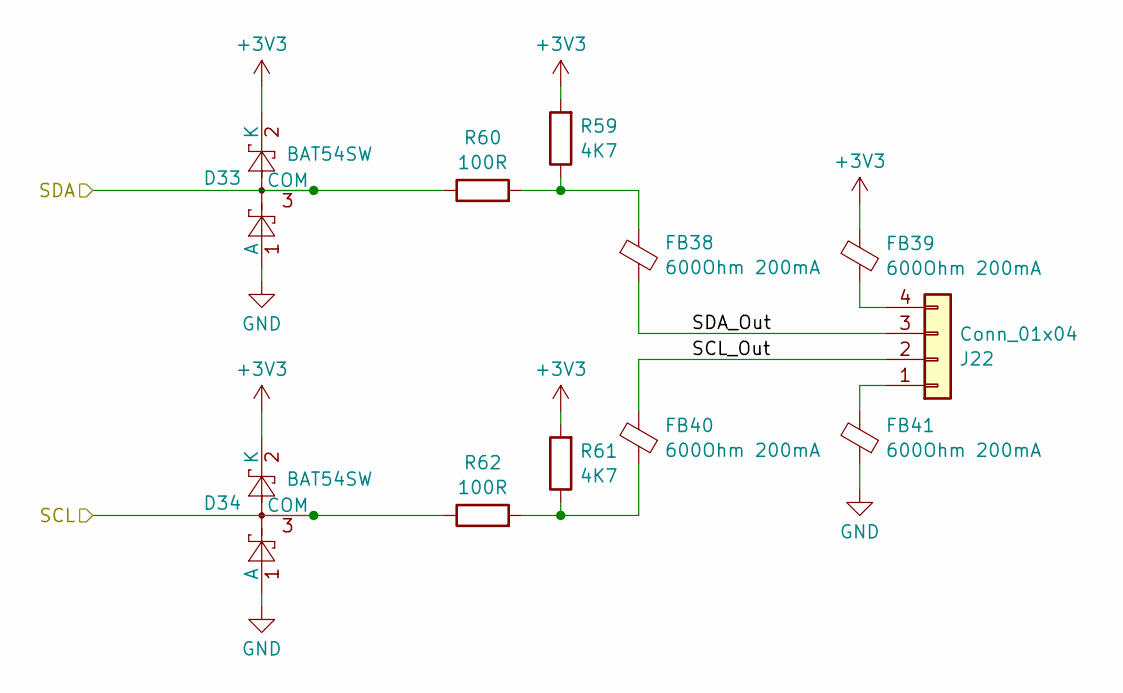
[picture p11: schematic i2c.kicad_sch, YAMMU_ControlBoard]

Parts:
D33, D34: BAT54SW; SOT-323_SC-70; JLCPCB Part # C78606
FB38, FB39, FB40, FB41: 600Ohm 200mA; L_0603_1608Metric; JLCPCB Part # C1002
J22: Conn_01x04; JST_XH_B4B-XH-A_1x04_P2.50mm_Vertical; JLCPCB Part # C7429634
R59, R61: 4K7; R_0603_1608Metric; JLCPCB Part # C23162
R60, R62: 100R; R_0603_1608Metric; JLCPCB Part # C22775

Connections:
+3V3: D33.2 (K), D34.2 (K), FB39.2, R59.2, R61.2; also elsewhere on the board
/I²C_Out/SCL_Out: FB40.2, J22.2
/I²C_Out/SDA_Out: FB38.2, J22.3
/MCU/I2C.SCL: D34.3 (COM), R62.1; also elsewhere on the board
/MCU/I2C.SDA: D33.3 (COM), R60.1; also elsewhere on the board
GND: D33.1 (A), D34.1 (A), FB41.1; also elsewhere on the board
unnamed: FB38.1, R59.1, R60.2
unnamed: FB40.1, R61.1, R62.2
unnamed: FB41.2, J22.1
unnamed: FB39.1, J22.4

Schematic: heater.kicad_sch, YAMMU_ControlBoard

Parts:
C18: 2,2µF; C_1206_3216Metric; JLCPCB Part # C50254
D26: SS34; D_SMA; JLCPCB Part # C8678
D27: RED; LED_0603_1608Metric; JLCPCB Part # C2286
F2: 10A; Fuseholder_Blade_Mini_Keystone_3568; JLCPCB Part # C19727305
FB26: 600Ohm 200mA; L_0603_1608Metric; JLCPCB Part # C1002
J19: Screw_Terminal_01x02; JL301-50002U02; JLCPCB Part # C395214
Q5: HY1904C2; PQFN-8-EP_6x5mm_P1.27mm_Generic; JLCPCB Part # C358116
R51: 20K; R_0603_1608Metric; JLCPCB Part # C4184
R52: 100R; R_0603_1608Metric; JLCPCB Part # C22775
R53: 47K; R_0603_1608Metric; JLCPCB Part # C25819

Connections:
/HeaterOut/EN_IN: FB26.1, R52.1
/HeaterOut/Enable: FB26.2; also elsewhere on the board
/HeaterOut/Gate: Q5.4 (G), R52.2, R53.1
/HeaterOut/Hout+: C18.1, D26.1 (K), F2.2, J19.2, R51.1
/HeaterOut/Hout-: C18.2, D26.2 (A), D27.1 (K), J19.1, Q5.5 (D)
/HeaterOut/LED_A: D27.2 (A), R51.2
/HeaterOut/Vin+: F2.1; also elsewhere on the board
/Vin-: Q5.1 (S), Q5.2 (S), Q5.3 (S), R53.2; also elsewhere on the board

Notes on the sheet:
Local GND Fill

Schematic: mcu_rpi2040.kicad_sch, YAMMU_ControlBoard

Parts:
IC2: RaspberryPi_Pico; RaspberryPi_Pico_SMD_HandSolder; JLCPCB Part # C7203002
SW1: SW_MEC_5E; SW_TS-1187A-B-A-B; JLCPCB Part # C318884

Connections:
+3V3: IC2.36 (3V3); also elsewhere on the board
+5V: IC2.39 (VSYS); also elsewhere on the board
/AnalogSensors/AnalogSignals.Belay: IC2.34 (GPIO28_ADC2); also elsewhere on the board
/AnalogSensors/AnalogSignals.TH0: IC2.31 (GPIO26_ADC0); also elsewhere on the board
/AnalogSensors/AnalogSignals.TH1: IC2.32 (GPIO27_ADC1); also elsewhere on the board
/AnalogSensors/Vref: IC2.35 (ADC_VREF); also elsewhere on the board
/EndStops/EndStop0: IC2.7 (GPIO5); also elsewhere on the board
/EndStops/EndStop1: IC2.11 (GPIO8); also elsewhere on the board
/EndStops/EndStop2: IC2.12 (GPIO9); also elsewhere on the board
/EndStops/EndStop3: IC2.14 (GPIO10); also elsewhere on the board
/FansOut/FanEnable0: IC2.16 (GPIO12); also elsewhere on the board
/FansOut/FanEnable1: IC2.17 (GPIO13); also elsewhere on the board
/FansOut/FanEnable2: IC2.19 (GPIO14); also elsewhere on the board
/HeaterOut/Enable: IC2.20 (GPIO15); also elsewhere on the board
/MCU/BLDC0.DIR: IC2.4 (GPIO2); also elsewhere on the board
/MCU/BLDC0.PWM: IC2.6 (GPIO4); also elsewhere on the board
/MCU/BLDC0.TACHO: IC2.5 (GPIO3); also elsewhere on the board
/MCU/BLDC1.PWM: IC2.10 (GPIO7); also elsewhere on the board
/MCU/BLDC1.TACHO: IC2.9 (GPIO6); also elsewhere on the board
/MCU/I2C.SCL: IC2.2 (GPIO1); also elsewhere on the board
/MCU/I2C.SDA: IC2.1 (GPIO0); also elsewhere on the board
/MCU/RGB.CLK: IC2.15 (GPIO11); also elsewhere on the board
/MCU/RGB.DATA: IC2.29 (GPIO22); also elsewhere on the board
/ServosOut/ServoSignal0: IC2.21 (GPIO16); also elsewhere on the board
/ServosOut/ServoSignal1: IC2.22 (GPIO17); also elsewhere on the board
/ServosOut/ServoSignal2: IC2.24 (GPIO18); also elsewhere on the board
/ServosOut/ServoSignal3: IC2.25 (GPIO19); also elsewhere on the board
/ServosOut/ServoSignal4: IC2.26 (GPIO20); also elsewhere on the board
/ServosOut/ServoSignal5: IC2.27 (GPIO21); also elsewhere on the board
AGND: IC2.33 (AGND); also elsewhere on the board
GND: IC2.3 (GND), IC2.8 (GND), IC2.13 (GND), IC2.18 (GND), IC2.23 (GND), IC2.28 (GND), IC2.38 (GND), IC2.D2 (GND), SW1.B; also elsewhere on the board
unnamed: IC2.30 (RUN), SW1.D

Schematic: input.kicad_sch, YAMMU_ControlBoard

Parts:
C2: 10nF; C_0603_1608Metric; JLCPCB Part # C57112
D2: BAT54SW; SOT-323_SC-70; JLCPCB Part # C78606
FB1: 600Ohm 200mA; L_0603_1608Metric; JLCPCB Part # C1002
J1: Conn_01x03; JST_XH_B3B-XH-A_1x03_P2.50mm_Vertical; JLCPCB Part # C7429633
R3: 150K; R_0603_1608Metric; JLCPCB Part # C22807
R5: 10K; R_0603_1608Metric; JLCPCB Part # C25804
R7: 150K; R_0603_1608Metric; JLCPCB Part # C22807; not fitted

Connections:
+3V3: D2.2 (K), R3.1; also elsewhere on the board
/EndStops/EndStop0: C2.1, D2.3 (COM), R3.2, R5.2, R7.1; also elsewhere on the board
/EndStops/Input0/GNDin: J1.2; also elsewhere on the board
/EndStops/Input0/Input_In: FB1.1, J1.1
/EndStops/Input0/Vin: J1.3; also elsewhere on the board
GND: C2.2, D2.1 (A), R7.2; also elsewhere on the board
unnamed: FB1.2, R5.1

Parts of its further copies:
C4, C5, C14: 10nF; C_0603_1608Metric; JLCPCB Part # C57112
D7, D11, D17: BAT54SW; SOT-323_SC-70; JLCPCB Part # C78606
FB6, FB11, FB16: 600Ohm 200mA; L_0603_1608Metric; JLCPCB Part # C1002
J4, J7, J11: Conn_01x03; JST_XH_B3B-XH-A_1x03_P2.50mm_Vertical; JLCPCB Part # C7429633
R16, R28, R39: 150K; R_0603_1608Metric; JLCPCB Part # C22807
R18, R29, R40: 10K; R_0603_1608Metric; JLCPCB Part # C25804
R20, R30, R41: 150K; R_0603_1608Metric; JLCPCB Part # C22807; not fitted

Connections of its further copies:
+3V3: D7.2 (K), D11.2 (K), D17.2 (K), R16.1, R28.1, R39.1; also elsewhere on the board
/EndStops/EndStop1: C4.1, D7.3 (COM), R16.2, R18.2, R20.1; also elsewhere on the board
/EndStops/EndStop2: C5.1, D11.3 (COM), R28.2, R29.2, R30.1; also elsewhere on the board
/EndStops/EndStop3: C14.1, D17.3 (COM), R39.2, R40.2, R41.1; also elsewhere on the board
/EndStops/Input0/GNDin: J4.2, J7.2, J11.2; also elsewhere on the board
/EndStops/Input0/Vin: J4.3, J7.3, J11.3; also elsewhere on the board
/EndStops/Input1/Input_In: FB6.1, J4.1
/EndStops/Input2/Input_In: FB11.1, J7.1
/EndStops/Input3/Input_In: FB16.1, J11.1
GND: C4.2, C5.2, C14.2, D7.1 (A), D11.1 (A), D17.1 (A), R20.2, R30.2, R41.2; also elsewhere on the board
unnamed: FB6.2, R18.1
unnamed: FB11.2, R29.1
unnamed: FB16.2, R40.1

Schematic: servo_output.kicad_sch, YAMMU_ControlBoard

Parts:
D21: BAT54SW; SOT-323_SC-70; JLCPCB Part # C78606
FB18: 600Ohm 200mA; L_0603_1608Metric; JLCPCB Part # C1002
J13: Conn_01x03_Pin; PinHeader_1x03_P2.54mm_Vertical_HighDensity; JLCPCB Part # C49257
R42: 220R; R_0603_1608Metric; JLCPCB Part # C22962

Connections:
+3V3: D21.2 (K); also elsewhere on the board
/ServosOut/Servo0/GNDservo: J13.1; also elsewhere on the board
/ServosOut/Servo0/Signal_out: FB18.2, J13.3
/ServosOut/Servo0/Vservo: J13.2; also elsewhere on the board
/ServosOut/ServoSignal0: D21.3 (COM), R42.1; also elsewhere on the board
GND: D21.1 (A); also elsewhere on the board
unnamed: FB18.1, R42.2

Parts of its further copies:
D4, D9, D15, D23, D25: BAT54SW; SOT-323_SC-70; JLCPCB Part # C78606
FB4, FB9, FB13, FB22, FB25: 600Ohm 200mA; L_0603_1608Metric; JLCPCB Part # C1002
J3, J6, J10, J15, J17: Conn_01x03_Pin; PinHeader_1x03_P2.54mm_Vertical_HighDensity; JLCPCB Part # C49257
R9, R22, R32, R47, R50: 220R; R_0603_1608Metric; JLCPCB Part # C22962

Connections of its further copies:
+3V3: D4.2 (K), D9.2 (K), D15.2 (K), D23.2 (K), D25.2 (K); also elsewhere on the board
/ServosOut/Servo0/GNDservo: J3.1, J6.1, J10.1, J15.1, J17.1; also elsewhere on the board
/ServosOut/Servo0/Vservo: J3.2, J6.2, J10.2, J15.2, J17.2; also elsewhere on the board
/ServosOut/Servo1/Signal_out: FB4.2, J3.3
/ServosOut/Servo2/Signal_out: FB9.2, J6.3
/ServosOut/Servo3/Signal_out: FB13.2, J10.3
/ServosOut/Servo4/Signal_out: FB22.2, J15.3
/ServosOut/Servo5/Signal_out: FB25.2, J17.3
/ServosOut/ServoSignal1: D4.3 (COM), R9.1; also elsewhere on the board
/ServosOut/ServoSignal2: D9.3 (COM), R22.1; also elsewhere on the board
/ServosOut/ServoSignal3: D15.3 (COM), R32.1; also elsewhere on the board
/ServosOut/ServoSignal4: D23.3 (COM), R47.1; also elsewhere on the board
/ServosOut/ServoSignal5: D25.3 (COM), R50.1; also elsewhere on the board
GND: D4.1 (A), D9.1 (A), D15.1 (A), D23.1 (A), D25.1 (A); also elsewhere on the board
unnamed: FB4.1, R9.2
unnamed: FB9.1, R22.2
unnamed: FB13.1, R32.2
unnamed: FB22.1, R47.2
unnamed: FB25.1, R50.2

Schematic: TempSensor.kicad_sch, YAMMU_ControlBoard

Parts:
C16: 100nF; C_0603_1608Metric; JLCPCB Part # C14663
D22: BAT54SW; SOT-323_SC-70; JLCPCB Part # C78606
FB21: 600Ohm 200mA; L_0603_1608Metric; JLCPCB Part # C1002
J14: Conn_01x02; JST_XH_B2B-XH-A_1x02_P2.50mm_Vertical; JLCPCB Part # C18077833
R45: 47K; R_0603_1608Metric; JLCPCB Part # C25819
R46: 4K7; R_0603_1608Metric; JLCPCB Part # C23162

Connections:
+3V3: D22.2 (K); also elsewhere on the board
/AnalogSensors/AnalogSignals.TH0: C16.1, D22.3 (COM), R46.2; also elsewhere on the board
/AnalogSensors/Belay/GNDsensor: J14.1; also elsewhere on the board
/AnalogSensors/Vref: R45.1; also elsewhere on the board
AGND: C16.2; also elsewhere on the board
GND: D22.1 (A); also elsewhere on the board
unnamed: FB21.2, R45.2, R46.1
unnamed: FB21.1, J14.2

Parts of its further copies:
C17: 100nF; C_0603_1608Metric; JLCPCB Part # C14663
D24: BAT54SW; SOT-323_SC-70; JLCPCB Part # C78606
FB24: 600Ohm 200mA; L_0603_1608Metric; JLCPCB Part # C1002
J16: Conn_01x02; JST_XH_B2B-XH-A_1x02_P2.50mm_Vertical; JLCPCB Part # C18077833
R48: 47K; R_0603_1608Metric; JLCPCB Part # C25819
R49: 4K7; R_0603_1608Metric; JLCPCB Part # C23162

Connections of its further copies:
+3V3: D24.2 (K); also elsewhere on the board
/AnalogSensors/AnalogSignals.TH1: C17.1, D24.3 (COM), R49.2; also elsewhere on the board
/AnalogSensors/Belay/GNDsensor: J16.1; also elsewhere on the board
/AnalogSensors/Vref: R48.1; also elsewhere on the board
AGND: C17.2; also elsewhere on the board
GND: D24.1 (A); also elsewhere on the board
unnamed: FB24.2, R48.2, R49.1
unnamed: FB24.1, J16.2

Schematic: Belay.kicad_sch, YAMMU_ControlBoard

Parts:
C22: 100nF; C_0603_1608Metric; JLCPCB Part # C14663
D35: BAT54SW; SOT-323_SC-70; JLCPCB Part # C78606
FB42, FB43: 600Ohm 200mA; L_0603_1608Metric; JLCPCB Part # C1002
J23: Conn_01x03; JST_XH_B3B-XH-A_1x03_P2.50mm_Vertical; JLCPCB Part # C7429633
R63: 4K7; R_0603_1608Metric; JLCPCB Part # C23162

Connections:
+3V3: D35.2 (K); also elsewhere on the board
/AnalogSensors/AnalogSignals.Belay: C22.1, D35.3 (COM), R63.2; also elsewhere on the board
/AnalogSensors/Belay/GNDsensor: J23.2; also elsewhere on the board
/AnalogSensors/Vref: FB42.2; also elsewhere on the board
AGND: C22.2; also elsewhere on the board
GND: D35.1 (A); also elsewhere on the board
unnamed: FB43.2, R63.1
unnamed: FB43.1, J23.1
unnamed: FB42.1, J23.3

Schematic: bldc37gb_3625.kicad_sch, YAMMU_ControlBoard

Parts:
C1: 1nF; C_0603_1608Metric; JLCPCB Part # C1588
C23: 100nF; C_0603_1608Metric; JLCPCB Part # C14663
D1, D3: BAT54SW; SOT-323_SC-70; JLCPCB Part # C78606
D5: BZT52C4V7S; D_SOD-323; JLCPCB Part # C19077439
FB2, FB3, FB5: 600Ohm 200mA; L_0603_1608Metric; JLCPCB Part # C1002
J2: Conn_01x05; JST_XH_B5B-XH-A_1x05_P2.50mm_Vertical; JLCPCB Part # C7429635
Q1: 2N7002; SOT-23; JLCPCB Part # C8545
R1: 0R; R_0603_1608Metric; JLCPCB Part # C21189; not fitted
R2: 150K; R_0603_1608Metric; JLCPCB Part # C22807; not fitted
R4: 10K; R_0603_1608Metric; JLCPCB Part # C25804
R6, R10: 150K; R_0603_1608Metric; JLCPCB Part # C22807
R8, R11: 220R; R_0603_1608Metric; JLCPCB Part # C22962
R12: 100R; R_0603_1608Metric; JLCPCB Part # C22775
R13: 47K; R_0603_1608Metric; JLCPCB Part # C25819
U1: SN74AHCT1G86DBVR; SOT-23-5; JLCPCB Part # C43417

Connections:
+3V3: C23.1, D1.2 (K), D3.2 (K), R2.1, U1.5 (VCC); also elsewhere on the board
/MCU/BLDC1.PWM: R12.1, U1.2; also elsewhere on the board
/MCU/BLDC1.TACHO: C1.1, D1.3 (COM), R2.2, R4.1, R6.1; also elsewhere on the board
/Motors/BLDC0/GND_Mot: J2.1; also elsewhere on the board
/Motors/BLDC0/V_Mot: J2.2; also elsewhere on the board
/Motors/BLDC1.DIR: R1.1, U1.1; also elsewhere on the board
/Motors/BLDC1/DIR_Mot: FB3.1, J2.5
/Motors/BLDC1/PWM_Mot: FB5.1, J2.4
/Motors/BLDC1/Tacho_Mot: FB2.2, J2.3
GND: C1.2, C23.2, D1.1 (A), D3.1 (A), D5.2 (A), Q1.2 (S), R6.2, R13.1, U1.3 (GND); also elsewhere on the board
unnamed: D3.3 (COM), R1.2, R8.1, U1.4
unnamed: D5.1 (K), Q1.3 (D), R10.1, R11.1
unnamed: FB2.1, R4.2
unnamed: FB3.2, R8.2
unnamed: FB5.2, R11.2
unnamed: Q1.1 (G), R12.2, R13.2
VSS: R10.2; also elsewhere on the board

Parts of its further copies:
C3: 1nF; C_0603_1608Metric; JLCPCB Part # C1588
C24: 100nF; C_0603_1608Metric; JLCPCB Part # C14663
D6, D8: BAT54SW; SOT-323_SC-70; JLCPCB Part # C78606
D10: BZT52C4V7S; D_SOD-323; JLCPCB Part # C19077439
FB7, FB8, FB10: 600Ohm 200mA; L_0603_1608Metric; JLCPCB Part # C1002
J5: Conn_01x05; JST_XH_B5B-XH-A_1x05_P2.50mm_Vertical; JLCPCB Part # C7429635
Q2: 2N7002; SOT-23; JLCPCB Part # C8545
R14: 0R; R_0603_1608Metric; JLCPCB Part # C21189; not fitted
R15: 150K; R_0603_1608Metric; JLCPCB Part # C22807; not fitted
R17: 10K; R_0603_1608Metric; JLCPCB Part # C25804
R19, R23: 150K; R_0603_1608Metric; JLCPCB Part # C22807
R21, R24: 220R; R_0603_1608Metric; JLCPCB Part # C22962
R25: 100R; R_0603_1608Metric; JLCPCB Part # C22775
R26: 47K; R_0603_1608Metric; JLCPCB Part # C25819
U2: SN74AHCT1G86DBVR; SOT-23-5; JLCPCB Part # C43417

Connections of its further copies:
+3V3: C24.1, D6.2 (K), D8.2 (K), R15.1, U2.5 (VCC); also elsewhere on the board
/MCU/BLDC0.DIR: R14.1, U2.1; also elsewhere on the board
/MCU/BLDC0.PWM: R25.1, U2.2; also elsewhere on the board
/MCU/BLDC0.TACHO: C3.1, D6.3 (COM), R15.2, R17.1, R19.1; also elsewhere on the board
/Motors/BLDC0/DIR_Mot: FB8.1, J5.5
/Motors/BLDC0/GND_Mot: J5.1; also elsewhere on the board
/Motors/BLDC0/PWM_Mot: FB10.1, J5.4
/Motors/BLDC0/Tacho_Mot: FB7.2, J5.3
/Motors/BLDC0/V_Mot: J5.2; also elsewhere on the board
GND: C3.2, C24.2, D6.1 (A), D8.1 (A), D10.2 (A), Q2.2 (S), R19.2, R26.1, U2.3 (GND); also elsewhere on the board
unnamed: D8.3 (COM), R14.2, R21.1, U2.4
unnamed: D10.1 (K), Q2.3 (D), R23.1, R24.1
unnamed: FB7.1, R17.2
unnamed: FB8.2, R21.2
unnamed: FB10.2, R24.2
unnamed: Q2.1 (G), R25.2, R26.2
VSS: R23.2; also elsewhere on the board

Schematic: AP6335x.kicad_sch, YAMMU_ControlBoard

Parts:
C1.1, C1.2, C1.3, C1.4, C1.5, C1.6, C1.7: 10µF 50V; C_1206_3216Metric; JLCPCB Part # C13585
C2.1, C2.2, C2.3, C2.4: 100µF/6,3V; C_1206_3216Metric; JLCPCB Part # C15008
C3.1: 100nF; C_0603_1608Metric; JLCPCB Part # C14663
C4.1: 47pF; C_0603_1608Metric; JLCPCB Part # C1671
C5.1: 3,3nF; C_0603_1608Metric; JLCPCB Part # C1613
IC1: AP63356DV-7; AP63356DV7; Mouser Part Number 621-AP63356DV-7
L1: 6,8µH; L_APV_APH0530; JLCPCB Part # C325965
R1.1: 105K; R_0603_1608Metric; JLCPCB Part # C16840
R2.1: 20K; R_0603_1608Metric; JLCPCB Part # C4184
R3.1: 47K; R_0603_1608Metric; JLCPCB Part # C25819
R4.1: 10K; R_0603_1608Metric; JLCPCB Part # C25804
R5.1: 38K3; R_0603_1608Metric; JLCPCB Part # C23034

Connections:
+5V: C2.1.1, C2.2.1, C2.3.1, C2.4.1, C4.1.2, L1.2, R1.1.1; also elsewhere on the board
/Power/Vreg/BST: C3.1.1, IC1.6 (BST)
/Power/Vreg/COMP: IC1.4 (COMP), R5.1.1
/Power/Vreg/EN: IC1.2 (EN), R3.1.2, R4.1.1
/Power/Vreg/FB: C4.1.1, IC1.3 (FB), R1.1.2, R2.1.1
/Power/Vreg/PG: IC1.5 (PG); also elsewhere on the board
/Power/Vreg/SW: C3.1.2, IC1.7 (SW), IC1.9 (SW), L1.1
GND: C1.1.2, C1.2.2, C1.3.2, C1.4.2, C1.5.2, C1.6.2, C1.7.2, C2.1.2, C2.2.2, C2.3.2, C2.4.2, C5.1.1, IC1.8 (GND), R2.1.2, R4.1.2; also elsewhere on the board
unnamed: C5.1.2, R5.1.2
VSS: C1.1.1, C1.2.1, C1.3.1, C1.4.1, C1.5.1, C1.6.1, C1.7.1, IC1.1 (VIN), R3.1.1; also elsewhere on the board

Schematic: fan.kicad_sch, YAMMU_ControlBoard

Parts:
C6: 2,2µF; C_1206_3216Metric; JLCPCB Part # C50254
D12: RED; LED_0603_1608Metric; JLCPCB Part # C2286
D13: 1N4148; D_SOD-323; JLCPCB Part # C2128
D14: SS34; D_SMA; JLCPCB Part # C8678
FB12, FB14: 600Ohm 3A; L_1206_3216Metric; JLCPCB Part # C357023
J8: Conn_01x02; JST_XH_B2B-XH-A_1x02_P2.50mm_Vertical; JLCPCB Part # C18077833
JP2: Jumper_3_Open; PinHeader_1x03_P2.54mm_Vertical_HighDensity; JLCPCB Part # C49257
Q3: AO3400A; SOT-23-3; JLCPCB Part # C20917
R27: 1K; R_0603_1608Metric; JLCPCB Part # C21190
R33: 100R; R_0603_1608Metric; JLCPCB Part # C22775
R34: 47K; R_0603_1608Metric; JLCPCB Part # C25819

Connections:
+3V3: D13.2 (A); also elsewhere on the board
+5V: JP2.1 (A); also elsewhere on the board
/FansOut/FanEnable0: R33.1; also elsewhere on the board
/FansOut/FanOut0/1N4148_A: D13.1 (K), R27.1
/FansOut/FanOut0/Fout+: FB12.2, J8.1
/FansOut/FanOut0/Fout-: FB14.1, J8.2
/FansOut/FanOut0/Gate: Q3.1 (G), R33.2, R34.1
/FansOut/FanOut0/LED_A: D12.2 (A), R27.2
GND: Q3.2 (S), R34.2; also elsewhere on the board
unnamed: C6.2, D12.1 (K), D14.2 (A), FB14.2, Q3.3 (D)
unnamed: C6.1, D14.1 (K), FB12.1, JP2.2 (C)
VSS: JP2.3 (B); also elsewhere on the board

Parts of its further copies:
C15, C19: 2,2µF; C_1206_3216Metric; JLCPCB Part # C50254
D18, D28: RED; LED_0603_1608Metric; JLCPCB Part # C2286
D19, D29: 1N4148; D_SOD-323; JLCPCB Part # C2128
D20, D30: SS34; D_SMA; JLCPCB Part # C8678
FB17, FB19, FB31, FB32: 600Ohm 3A; L_1206_3216Metric; JLCPCB Part # C357023
J12, J20: Conn_01x02; JST_XH_B2B-XH-A_1x02_P2.50mm_Vertical; JLCPCB Part # C18077833
JP3, JP4: Jumper_3_Open; PinHeader_1x03_P2.54mm_Vertical_HighDensity; JLCPCB Part # C49257
Q4, Q6: AO3400A; SOT-23-3; JLCPCB Part # C20917
R38, R54: 1K; R_0603_1608Metric; JLCPCB Part # C21190
R43, R55: 100R; R_0603_1608Metric; JLCPCB Part # C22775
R44, R56: 47K; R_0603_1608Metric; JLCPCB Part # C25819

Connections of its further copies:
+3V3: D19.2 (A), D29.2 (A); also elsewhere on the board
+5V: JP3.1 (A), JP4.1 (A); also elsewhere on the board
/FansOut/FanEnable1: R43.1; also elsewhere on the board
/FansOut/FanEnable2: R55.1; also elsewhere on the board
/FansOut/FanOut1/1N4148_A: D19.1 (K), R38.1
/FansOut/FanOut1/Fout+: FB17.2, J12.1
/FansOut/FanOut1/Fout-: FB19.1, J12.2
/FansOut/FanOut1/Gate: Q4.1 (G), R43.2, R44.1
/FansOut/FanOut1/LED_A: D18.2 (A), R38.2
/FansOut/FanOut2/1N4148_A: D29.1 (K), R54.1
/FansOut/FanOut2/Fout+: FB31.2, J20.1
/FansOut/FanOut2/Fout-: FB32.1, J20.2
/FansOut/FanOut2/Gate: Q6.1 (G), R55.2, R56.1
/FansOut/FanOut2/LED_A: D28.2 (A), R54.2
GND: Q4.2 (S), Q6.2 (S), R44.2, R56.2; also elsewhere on the board
unnamed: C15.2, D18.1 (K), D20.2 (A), FB19.2, Q4.3 (D)
unnamed: C15.1, D20.1 (K), FB17.1, JP3.2 (C)
unnamed: C19.2, D28.1 (K), D30.2 (A), FB32.2, Q6.3 (D)
unnamed: C19.1, D30.1 (K), FB31.1, JP4.2 (C)
VSS: JP3.3 (B), JP4.3 (B); also elsewhere on the board

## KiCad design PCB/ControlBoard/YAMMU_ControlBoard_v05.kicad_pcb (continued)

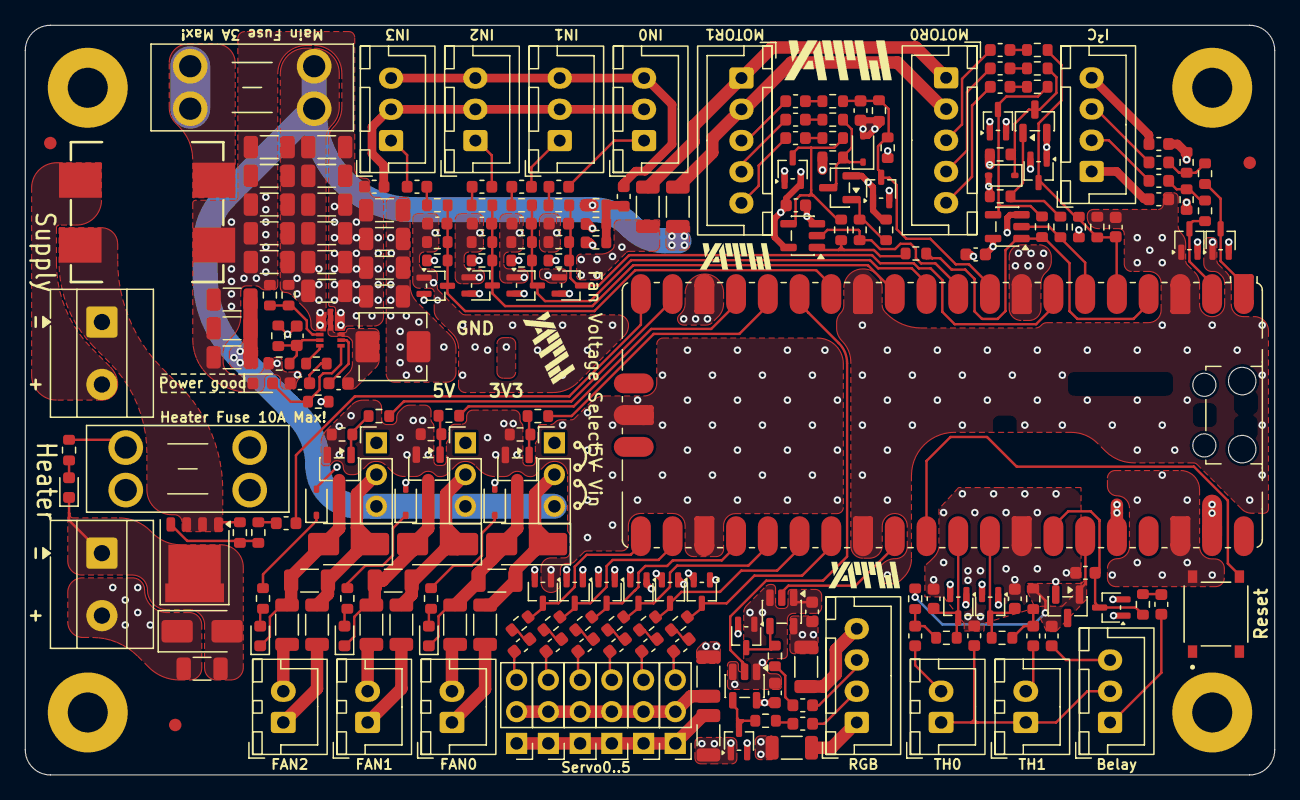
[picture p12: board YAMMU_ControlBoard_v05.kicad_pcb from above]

Board: 8 copper layers, 100.0 x 60.0 mm, 234 parts (0 on the bottom side), 137 nets.

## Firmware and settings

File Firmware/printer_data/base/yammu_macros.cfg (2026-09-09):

# YAMMU Macros Configuration File
# This file contains macros specific to the YAMMU (Yet Another Multi-Material Unit)

[gcode_macro _YAMMU_SELECT_TOOL]
description: "Selects the specified tool/gate on YAMMU"
variable_select_angle: [0, 180, 0, 180, 0, 180, 0, 180]
variable_rest_angle: [90, 90, 90, 90, 90, 90, 90, 90]
gcode:
  {% set GATE  = params.GATE|int %}

  {% set PREFIX = "MMU_SERVO_" %}
  {% set SELECTED_SERVO = (GATE // 2) %}
  {% set OLD_GATE = printer.mmu.gate_selected %}

  {% if OLD_GATE != GATE %}
    ; {% for i in range(printer.mmu.num_gates // 2) %}
    {% for i in range(3) %}
      {% set SERVO = PREFIX ~ i %}

      {% if SELECTED_SERVO == i %}
        RESPOND MSG="SET_SERVO SERVO={SERVO} ANGLE={select_angle[GATE]}"
        SET_SERVO SERVO={SERVO} ANGLE={select_angle[GATE]}  ; Move servo to select position
      {% else %}
        RESPOND MSG="SET_SERVO SERVO={SERVO} ANGLE={rest_angle[i]}"
        SET_SERVO SERVO={SERVO} ANGLE={rest_angle[i]}  ; Move servo to rest position
      {% endif %}
    {% endfor %}

  {% else %}
    {% set SERVO = PREFIX ~ SELECTED_SERVO %}
    RESPOND MSG="SET_SERVO SERVO={SERVO} ANGLE={select_angle[GATE]}"
    SET_SERVO SERVO={SERVO} ANGLE={select_angle[GATE]}  ; Move servo to select position

  {% endif %}

[gcode_macro _YAMMU_FORM_TIP]
description: "Standalone macro that mimics Superslicer process"
gcode:
  {% set OLD_GATE = printer.mmu.gate_selected %}
  MMU_SYNC_GEAR_MOTOR SYNC=0
  _YAMMU_SELECT_TOOL GATE=-1

  _MMU_FORM_TIP

  MMU_SYNC_GEAR_MOTOR SYNC=1
  _YAMMU_SELECT_TOOL GATE={OLD_GATE}

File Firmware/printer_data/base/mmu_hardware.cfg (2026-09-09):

########################################################################################################################
# Happy Hare MMU Software
#
# EDIT THIS FILE BASED ON YOUR SETUP
#
# Copyright (C) 2022-2025  moggieuk#6538 (discord)
#                          moggieuk@hotmail.com
# This file may be distributed under the terms of the GNU GPLv3 license.
#
# Goal: Happy Hare MMU hardware config file with config for unknown MCU board
#
# (\_/)
# ( *,*)
# (")_(") Happy Hare Ready
#
#
# Notes about setup of common external MCUs can be found here:
#  https://github.com/moggieuk/Happy-Hare/blob/main/doc/mcu_notes.md
#
# Note about "touch" endstops: Happy Hare provides extremely flexible homing options using both single steppers or
# synced steppers. The "touch" option leverages stallguard and thus requires the appropriate 'diag_pin' and stallguard
# parameters set on the TMC driver section. If you have the diag_pin exposed, it is harmless to define this because
# they will only be used when explicitly needed and configured.
#
# Touch option for each stepper provides these benefits / possibilities (experimental):
#  - on extruder stepper allows for the automatic detection of the nozzle!
#  - on selector stepper allows for the automatic detection of filament stuck in the gate and subsequent recovery
#  - on gear stepper allows for the automatic detection of the extruder entrance
#
# In summary, "touch" homing with your MMU is an advanced option that requires patience and careful tuning. Everything
# works with regular endstops and there are workaround options for certain homing points (like extruder entry) in
# the absence of any endstop. I'm really interested in creative setups. Ping me on Discord (moggieuk#6538)
#
# See 'mmu.cfg' for serial definition and pins aliases
#
# HOMING CAPABLE EXTRUDER (VERY ADVANCED) -----------------------------------------------------------------------------
# With Happy Hare installed even the extruder can be homed. You will find the usual 'endstop' parameters can be added
# to your '[extruder]' section.  Useless you have some clever load cell attached to your nozzle it only really makes
# sense to configure stallguard style "touch" homing. To do this add lines similar to this to your existing
# '[extruder]' definition in printer.cfg.
#
#    [extruder]
#    endstop_pin: tmc2209_extruder:virtual_endstop
#
# Also be sure to add the appropriate stallguard config to the TMC section, e.g.
#
#    [tmc2209 extruder]
#    diag_pin: E_DIAG		# Set to MCU pin connected to TMC DIAG pin for extruder
#    driver_SGTHRS: 100		# 255 is most sensitive value, 0 is least sensitive
#
# Happy Hare will take care of the rest and add a 'mmu_ext_touch' endstop automatically
#

# MMU MACHINE / TYPE ---------------------------------------------------------------------------------------------------
# ███╗   ███╗███╗   ███╗██╗   ██╗    ███╗   ███╗ █████╗  ██████╗██╗  ██╗██╗███╗   ██╗███████╗
# ████╗ ████║████╗ ████║██║   ██║    ████╗ ████║██╔══██╗██╔════╝██║  ██║██║████╗  ██║██╔════╝
# ██╔████╔██║██╔████╔██║██║   ██║    ██╔████╔██║███████║██║     ███████║██║██╔██╗ ██║█████╗
# ██║╚██╔╝██║██║╚██╔╝██║██║   ██║    ██║╚██╔╝██║██╔══██║██║     ██╔══██║██║██║╚██╗██║██╔══╝
# ██║ ╚═╝ ██║██║ ╚═╝ ██║╚██████╔╝    ██║ ╚═╝ ██║██║  ██║╚██████╗██║  ██║██║██║ ╚████║███████╗
# ╚═╝     ╚═╝╚═╝     ╚═╝ ╚═════╝     ╚═╝     ╚═╝╚═╝  ╚═╝ ╚═════╝╚═╝  ╚═╝╚═╝╚═╝  ╚═══╝╚══════╝
[mmu_machine]

# Number of selectable gate on (each) MMU. Generally this is a single number, but with multi-mmu (type-B) setups
# it can be a comma separated list of the number of gates per unit.
# E.g. 'num_gates: 4,4,2' for a 2xBox Turtle and 1xNight Owl multiplexed setup.
# Unit names are zero-based and map directly to these groups: unit0 owns the first group, unit1 the next, etc.
#
num_gates: 4,4

# MMU Vendor & Version is used to automatically configure some parameters and validate configuration
# If custom set to "Other" and uncomment the additional parameters below
#
# ERCF          1.1  add "s" suffix for Springy, "b" for Binky, "t" for Triple-Decky
#                    e.g. "1.1sb" for v1.1 with Springy mod and Binky encoder
# ERCF          2.0  community edition ERCFv2
# ERCF          2.5
# Tradrack      1.0  add "e" if encoder is fitted (assumed to be Binky)
# AngryBeaver   1.0
# BoxTurtle     1.0
# NightOwl      1.0
# 3MS           1.0
# 3D Chameleon  1.0
# Pico          1.0
# Prusa         3.0  NOT YET SUPPORTED - COMING SOON
# Other              Generic setup that may require further customization of 'cad' parameters. See doc in mmu_parameters.cfg
#
mmu_vendor: Other			# MMU family
mmu_version: 1.0			# MMU hardware version number (add mod suffix documented above)
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

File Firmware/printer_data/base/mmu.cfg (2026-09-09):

########################################################################################################################
# Happy Hare MMU Software
#
# EDIT THIS FILE BASED ON YOUR SETUP
#
# Copyright (C) 2022-2025  moggieuk#6538 (discord)
#                          moggieuk@hotmail.com
# This file may be distributed under the terms of the GNU GPLv3 license.
#
# Goal: Happy Hare MMU hardware pin config
#
# (\_/)
# ( *,*)
# (")_(") Happy Hare Ready
#
#
# This contains aliases for pins for MCU type unknown
#
[mcu mmu]
serial: /dev/serial/by-id/usb-Klipper_rp2040_E66488C15F3E1835-if00	# Change to `canbus_uuid: 1234567890` for CANbus setups

# PIN ALIASES FOR MMU MCU BOARD ----------------------------------------------------------------------------------------
# ██████╗ ██╗███╗   ██╗     █████╗ ██╗     ██╗ █████╗ ███████╗
# ██╔══██╗██║████╗  ██║    ██╔══██╗██║     ██║██╔══██╗██╔════╝
# ██████╔╝██║██╔██╗ ██║    ███████║██║     ██║███████║███████╗
# ██╔═══╝ ██║██║╚██╗██║    ██╔══██║██║     ██║██╔══██║╚════██║
# ██║     ██║██║ ╚████║    ██║  ██║███████╗██║██║  ██║███████║
# ╚═╝     ╚═╝╚═╝  ╚═══╝    ╚═╝  ╚═╝╚══════╝╚═╝╚═╝  ╚═╝╚══════╝
# Section to create alias for pins used by MMU for easier integration into Klippain and RatOS. The names match those
# referenced in the mmu_hardware.cfg file. If you get into difficulty you can also comment out this aliases definition
# completely and configure the pin names directly into mmu_hardware.cfg. However, use of aliases is encouraged.

# Note: that aliases are not created for TOOLHEAD_SENSOR, EXTRUDER_SENSOR or SYNC_FEEDBACK_SENSORS because those are
# most likely on the printer's main mcu. These should be set directly in mmu_hardware.cfg
#
# [board_pins mmu]
# mcu: mmu
# aliases:
#     BE=gpio28,  # Belay sensor
#     RGB=gpio22, # WS2812 RGB LED data pin
#     SDA=gpio0,  SCL=gpio1,  # I2C pins
#     TH0=gpio26, TH1=gpio27, # Thermistors
#     CW=gpio2,   RPM1=gpio3, M1=gpio4,   RPM2=gpio6, M2=gpio7,   # BLDC motor control
#     EN0=gpio5,  EN1=gpio8,  EN2=gpio9,  EN3=gpio10, EN4=gpio11, # Endstops
#     MF=gpio15, FAN0=gpio14, FAN1=gpio13, FAN2=gpio12,             # Heaters / Fans
#     S0=gpio16,  S1=gpio17,  S2=gpio18,  S3=gpio19,  S4=gpio20, S5=gpio21 # Servos

# [temperature_sensor th0]
# sensor_pin: mmu:gpio26
# sensor_type: Generic 3950
# min_temp: -200
# max_temp: 300

# [temperature_sensor th1]
# sensor_pin: mmu:gpio27
# sensor_type: Generic 3950
# min_temp: -200
# max_temp: 300

[board_pins mmu]
mcu: mmu # Assumes using an external / extra mcu dedicated to MMU
aliases:
    # MMU_ENCODER={encoder_pin},
    MMU_GATE_SENSOR_0=gpio5,
    MMU_GATE_SENSOR_1=gpio8,
    MMU_NEOPIXEL=gpio22,

    # YAMMU SERVOS
    MMU_SERVO_0=gpio16,
    MMU_SERVO_1=gpio17,
    MMU_SERVO_2=gpio18,
    MMU_SERVO_3=gpio19,

    # YAMMU ESPOOLER MOTORS
    YAMMU_BLDC_PWM_0=gpio4,
    YAMMU_BLDC_DIR_0=gpio2,
    YAMMU_BLDC_TACH_0=gpio21, #gpio3, # todo reconfigure pin
    YAMMU_BLDC_DIR_1=gpio20, # todo reconfigure pin
    YAMMU_BLDC_PWM_1=gpio7,
    YAMMU_BLDC_TACH_1=gpio11,

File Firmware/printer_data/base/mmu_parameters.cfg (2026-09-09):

########################################################################################################################
# Happy Hare MMU Software
#
# Template file for MMU's with Virtual Selector (Type-B designs like Box Turtle, Night Owl, Angry Beaver, ...)
# This file omits selector and selector-servo configuration and a few other options that don't make sense
#
# EDIT THIS FILE BASED ON YOUR SETUP
#
# Copyright (C) 2022-2026  moggieuk#6538 (discord)
#                          moggieuk@hotmail.com
# This file may be distributed under the terms of the GNU GPLv3 license.
#
# Goal: Main configuration parameters for the klipper module
#
# (\_/)
# ( *,*)
# (")_(") Happy Hare Ready
#
# Notes:
#   Macro configuration is specified separately in 'mmu_macro_vars.cfg'.
#   Full details in https://github.com/moggieuk/Happy-Hare/tree/main/doc/configuration.md
#
[mmu]
happy_hare_version: 3.42			# Don't mess, used for upgrade detection

# MMU Hardware Limits --------------------------------------------------------------------------------------------------
# ██╗     ██╗███╗   ███╗██╗████████╗███████╗
# ██║     ██║████╗ ████║██║╚══██╔══╝██╔════╝
# ██║     ██║██╔████╔██║██║   ██║   ███████╗
# ██║     ██║██║╚██╔╝██║██║   ██║   ╚════██║
# ███████╗██║██║ ╚═╝ ██║██║   ██║   ███████║
# ╚══════╝╚═╝╚═╝     ╚═╝╚═╝   ╚═╝   ╚══════╝
#
# Define the physical limits of your MMU. These settings will be respected regardless of individual speed settings.
#
gear_max_velocity: 300			# Never to be exceeded gear velocity regardless of specific parameters
gear_max_accel: 150				# Never to be exceeded gear acceleration regardless of specific parameters
selector_max_velocity: 250		# Never to be exceeded selector velocity regardless of specific parameters
selector_max_accel: 1200		# Never to be exceeded selector acceleration regardless of specific parameters


# Servo configuration  -------------------------------------------------------------------------------------------------
# ███████╗███████╗██████╗ ██╗   ██╗ ██████╗
# ██╔════╝██╔════╝██╔══██╗██║   ██║██╔═══██╗
# ███████╗█████╗  ██████╔╝██║   ██║██║   ██║
# ╚════██║██╔══╝  ██╔══██╗╚██╗ ██╔╝██║   ██║
# ███████║███████╗██║  ██║ ╚████╔╝ ╚██████╔╝
# ╚══════╝╚══════╝╚═╝  ╚═╝  ╚═══╝   ╚═════╝
#
# Angle of the servo in three named positions
#   up   = tool is selected and filament is allowed to freely move through gate
#   down = to grip filament
#   move = ready the servo for selector move (optional - defaults to up)
# V2.4.0 on: These positions are only for initial config they are replaced with calibrated servo positions in 'mmu_vars.cfg'
#
# Note that leaving the servo active when down can stress the electronics and is not recommended with EASY-BRD or ERB board
# unless the 5v power supply has been improved and it is not necessary with standard ERCF builds
# Make sure your hardware is suitable for the job!
#
servo_up_angle: 145			# ERCF: MG90S: 30  ; SAVOX SH0255MG: 140 ; Tradrack: 145
servo_down_angle: 30			# ERCF: MG90S: 140 ; SAVOX SH0255MG: 30  ; Tradrack: 1
servo_move_angle: 109			# Optional angle used when selector is moved (defaults to up position)
servo_duration: 0.4			# Duration of PWM burst sent to servo (default non-active mode, automatically turns off)
servo_dwell: 0.5			# Minimum time given to servo to complete movement prior to next move
servo_always_active: 0 			# CAUTION - WILL DAMAGE COMMON SERVOS, PLEASE USE AT YOUR OWN RISK: 1=Force servo to always stay active, 0=Release after movement
servo_active_down: 0			# CAUTION - WILL DAMAGE COMMON SERVOS, PLEASE USE AT YOUR OWN RISK: 1=Force servo to stay active when down only, 0=Release after movement
servo_buzz_gear_on_down: 0		# Whether to "buzz" the gear stepper on down to aid engagement
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

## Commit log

2026-07-04 Update CAD assembly file and remove obsolete deployment script; adjust Makefile for virtual environment package paths.
2026-07-15 Update CAD assembly files, replace deleted STL and add new outlet housing STL, and update sizes for existing files.
    [exhaust_housing.stl, outlet_housing.stl, y_splitter.stl]
2026-07-19 NEW ControlBoard!
    [AP6320x.kicad_sch, AP63356DV-7.stp, AP6335x.kicad_sch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]
2026-07-19 Added PCB-Shematic.pdf
2026-07-22 feat: refresh README and update electronics bay STLs
    Rework the README into a visual project overview and update the electronics bay printable parts, including the new DIN rail PSU mounts and renamed frame supports.
    [DIN_center_support_x3.stl, DIN_frame_mount_x6.stl, psu_bracket.stl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]
2026-07-22 Update Assembly.odp and Assembly.pdf files with new LFS object identifiers and sizes.
2026-07-24 Update CAD assembly file and add new hero SVG image; remove obsolete STL file and update others.
    [din_clip.stl, motor_housing_b_x2.stl, pcb_bracket.stl]
2026-07-24 Refactor PCB project structure by moving files from YAMMU_ControlBoard_v05_0 to ControlBoard, updating paths, and adding new images and README. Cleanup by removing obsolete files.
    [AP6320x.kicad_sch, AP63356DV-7.stp, AP6335x.kicad_sch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]
2026-08-12 Enhance README with calibration instructions
    Added calibration steps for BLDC motor and gear rotation distance in README.
2026-09-09 Updated various CAD and firmware files, added new addon configurations and STL files, removed obsolete configurations and STL files, modified existing files for improved functionality, and added new 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
    [5mm_shaft_cutting_guide.stl, DIN_center_support_x3.stl, DIN_corner_frame_mount_x4.stl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]
